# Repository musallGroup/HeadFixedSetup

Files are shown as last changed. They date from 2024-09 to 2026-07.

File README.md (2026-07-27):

# Head-fixed Behavior
This repository contains information about an open-source, multisensory head-fixed setup for operant conditioning. Here, we want to share all relevant information about the setup used in the publication ["Single-trial neural dynamics are dominated by richly varied movements"](https://www.nature.com/articles/s41593-019-0502-4) by Musall et al. One example of using the setup is the [PuffyPenguin](https://github.com/musallGroup/PuffyPenguin) paradigm for multisensory stimulation.

# Overview
Operant conditioning is essential for quantifying animal perception. We developed a head-fixed setup to measure the behavioral output of animals while recording their brain activity with optophysiological and electrophysiological methods. This setup can perform a variety of protocols ranging from auditory, visual, and tactile to multi-sensory stimulation. The protocols themselves are highly customizable so that they can be tailored precisely to the respective research objective.

# Repository structure
```
docs/         MANUAL.md and wiring reference
software/     MATLAB: Autopilot GUI/scale reading, UDP client/server, local Bpod config
firmware/     Arduino/Teensy firmware for the touchshaker and RFID/weighing scale
              (firmware/openscale vendors SparkFun's OpenScale firmware)
hardware/     STL enclosures and Altium/KiCAD PCB design files for the breakout and touchshaker boards
third_party/  Vendored Bpod_Gen2 framework
```
`third_party/bpod_gen2` and `firmware/openscale` vendor third-party projects with local
modifications on top; they are slated to become git submodules pointing at forks once those are
set up. If they've since been converted, initialize them after cloning with:
```
git submodule update --init --recursive
```

# Getting started
1. Clone this repository.
2. Initialize submodules (vendored dependencies): `git submodule update --init --recursive`
3. Follow the [manual](docs/MANUAL.md) to build the hardware and set up the software.

# Installation
Please refer to the [manual](docs/MANUAL.md) for detailed installation steps.

Connections

# Software
The setup runs on MATLAB, with Bpod handling the behavioral state machine. For the full
step-by-step walkthrough of starting MATLAB, calibrating spouts, and running a session, see
[Running a session](docs/MANUAL.md#running-a-session) in the manual.

# Future
Stay tuned for new paradigms and new features of the head-fixed setup. Currently we are working
on automation of data management and mouse detection.

# Citation
If you use this setup in your research, please cite:

> Musall, S., Kaufman, M.T., Juavinett, A.L., Gluf, S., Churchland, A.K. Single-trial neural
> dynamics are dominated by richly varied movements. *Nature Neuroscience* 22, 1677–1686 (2019).
> https://doi.org/10.1038/s41593-019-0502-4

```bibtex
@article{musall2019singletrial,
  title   = {Single-trial neural dynamics are dominated by richly varied movements},
  author  = {Musall, Simon and Kaufman, Matthew T. and Juavinett, Ashley L. and Gluf, Steven and Churchland, Anne K.},
  journal = {Nature Neuroscience},
  volume  = {22},
  number  = {10},
  pages   = {1677--1686},
  year    = {2019},
  doi     = {10.1038/s41593-019-0502-4}
}
```

# License
This project is licensed under the GNU General Public License v3.0 — see [LICENSE](LICENSE) for
details.

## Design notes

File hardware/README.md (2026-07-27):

# Hardware

3D-printable enclosures and PCB design files for the two custom boards used in this setup.

- [`breakout/`](breakout) — Breakout PCB (Altium originals + KiCAD import) and its enclosure
  (box + panels)
- [`touchshaker/`](touchshaker) — Touchshaker PCB (Altium originals + KiCAD import) and its
  enclosure (box + panels)
- [`platform/`](platform) — Animal platform and photodiode holder STLs

See [docs/MANUAL.md](../docs/MANUAL.md) for assembly instructions, wiring diagrams, and how these
parts fit together.

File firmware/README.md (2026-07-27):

# Firmware

Arduino/Teensy firmware for the setup's microcontroller-driven components.

- [`touchshaker/`](touchshaker) — Teensy 4.0 firmware for the Touchshaker box: reads the spout
  lick sensors and drives the spout motors
- [`rfid_scale/`](rfid_scale) — Teensy firmware that reads an RFID tag and a load cell together,
  for automated per-animal weighing
- [`openscale/`](openscale) — Vendored [SparkFun OpenScale](https://github.com/sparkfun/OpenScale)
  firmware, used by the weighing scale hardware

See [docs/MANUAL.md](../docs/MANUAL.md) for how these boards fit into the overall setup.

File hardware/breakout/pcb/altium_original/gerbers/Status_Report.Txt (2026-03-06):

Output: NC Drill Files
Type  : NC Drill
From  : Project [Breakout_v4.PrjPcb]
   Generated File[Breakout_v4-Plated.TXT]
   Generated File[Breakout_v4.LDP]
   Generated File[Breakout_v4.DRR]

Files Generated   : 3
Documents Printed : 0

Finished Output Generation At 07:50:04 On 23.02.2026

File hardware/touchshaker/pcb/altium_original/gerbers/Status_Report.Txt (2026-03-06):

Output: NC Drill Files
Type  : NC Drill
From  : Project [Bpod Controller v5.PrjPcb]
   Generated File[Bpod Controller v5-RoundHoles-Plated.TXT]
   Generated File[Bpod Controller v5-SlotHoles-Plated.TXT]
   Generated File[Bpod Controller v5.LDP]
   Generated File[Bpod Controller v5.DRR]

Files Generated   : 4
Documents Printed : 0

Finished Output Generation At 08:42:49 On 10.02.2026

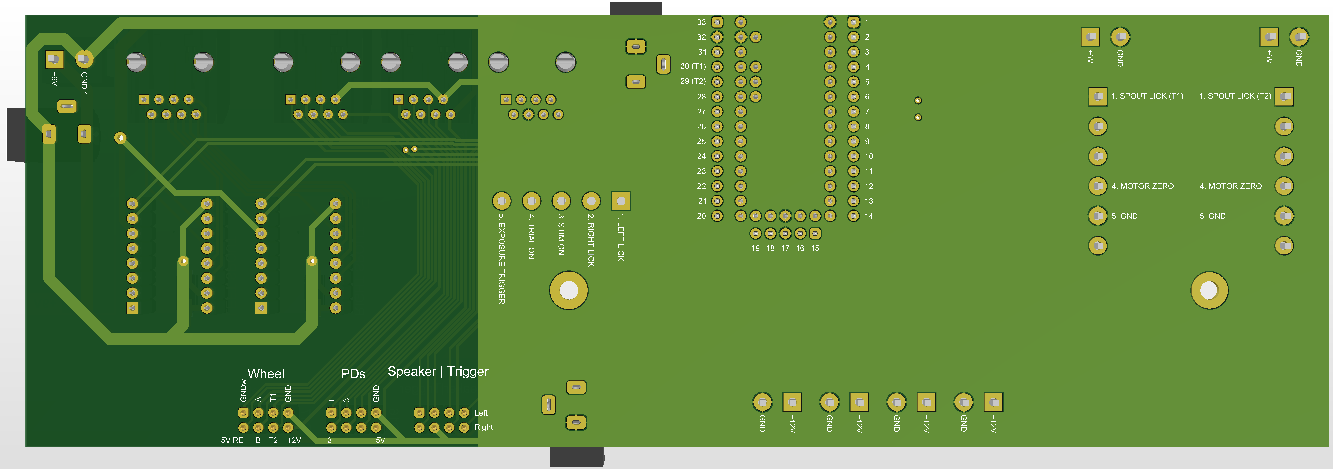
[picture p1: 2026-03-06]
hardware/touchshaker/pcb/altium_original/docs/Bpod_Controller_v5_bottom.png

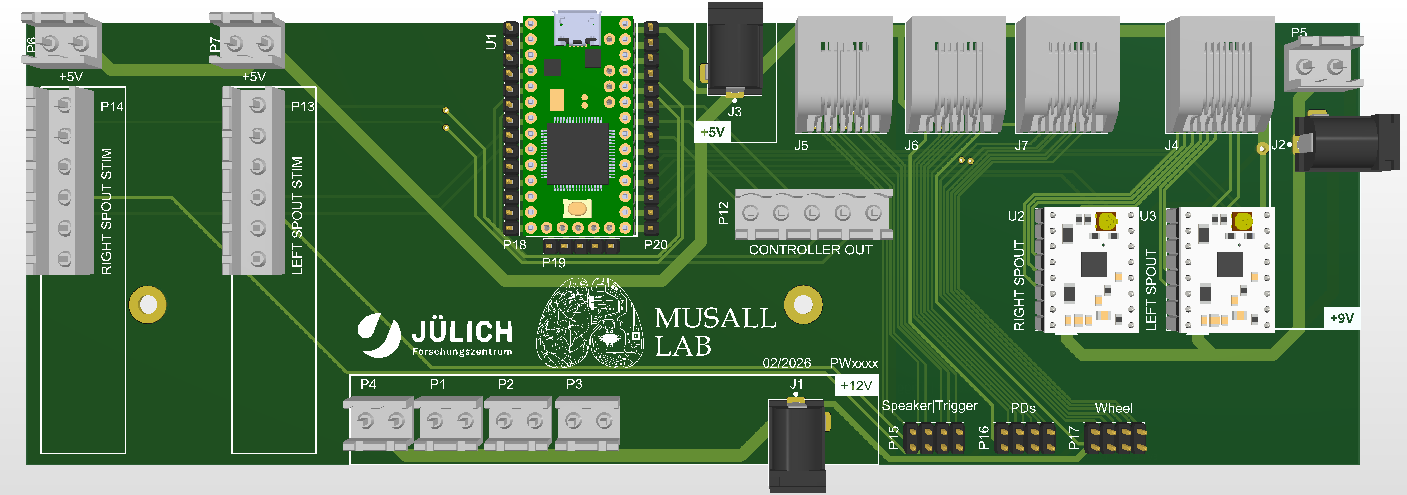
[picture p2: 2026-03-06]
hardware/touchshaker/pcb/altium_original/docs/Bpod_Controller_v5_top.png

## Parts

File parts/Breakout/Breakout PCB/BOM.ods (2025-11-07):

Line # | Name | Description | Quantity | Designator | Manufacturer 1 | Manufacturer Part Number 1
 | 870585774003 | Cap, 47Uf, 50V, Alu Elec, Hybrid, Rad Rohs Compliant: Yes |Wurth Elektronik 870585774003 | 1 | C1 | Wurth Elektronik | 870585774003
 | 10nF 0805 X7R 50V 5% | Kondensator 10nF 0805 X7R 50V 5% | 2 | C2, C4 | Vishay | VJ0805Y103JXAAC
 | 100nF 0805 X7R 100V | Kondensator 100nF 0805 X7R 100V 5% | 2 | C3, C5 | KEMET | C0805C104J1RACAUTO
 | 5569118-1 | Telecom and Datacom Connector, 8 Contact(s), Female, Right Angle, Solder Terminal, Locking, Jack | 4 | J1, J2, J3, J4 | TE Connectivity | 5569118-1
 | SL_1_025_4_ G | Fischer SL_1_025_4_ G, Stiftleiste, 1 Reiheb, 4 Pole, vergoldet | 3 | P1, P2, P3 | Fischer Elektronik | SL 1/025/36G
 | SL_1_025_2_ G | Fischer SL_1_025_2_ G, Stiftleiste, 1 Reiheb, 2 Pole, vergoldet | 11 | P4, P5, P6, P7, P8, P9, P10, P11, P12, P13, P14 | Fischer Elektronik | SL 1/025/36G
 | SL 2 025 8 G | Fischer SL 2 025 8 G, Stiftleiste, 2 Reiheb, 8 Pole, vergoldet | 1 | P15 | Fischer Elektronik | SL 2 025 72G
 | SL_1_025_1_ G | Fischer SL_1_025_1_ G, Stiftleiste, 1 Reiheb, 1 Pole, vergoldet | 4 | P16, P18, P19, P21 | Fischer Elektronik | SL 1/025/36G
 | SL_1_025_3_ G | Fischer SL_1_025_3_ G, Stiftleiste, 1 Reiheb, 3 Pole, vergoldet | 2 | P17, P20 | Fischer Elektronik | SL 1/025/36G
 | 10K 0805 200V 0,25W 0,5% 50ppm/K | Widerstand 10K 0805 200V 0,25W 0,5% 50ppm/K | 7 | R1, R2, R3, R5, R7, R8, R10 | KOA Speer | SG73G2ATTD1002D
 | 100R 1206 200V 0,25W 25ppm/K | Widerstans SMD 100R 1206 200V 0,25W 25ppm/K | 1 | R4 | Yageo Group | RT1206FRD07100RL
 | 5K 0805 100V 0,2W | Widerstand 5K 0805 100V 0,2W 25ppm/K | 2 | R6, R9 | Vishay | PNM0805E5001BST5
 | AT42QT1010-TSHR | Analog Circuit, 1 Func, PDSO6 ; Touchsensor; digital burst mode charge-transfer sensor ; | 2 | U1, U2 | Microchip | AT42QT1010-TSHR

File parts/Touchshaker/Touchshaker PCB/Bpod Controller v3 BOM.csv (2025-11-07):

Line # | Name | Description | Designator | Quantity | Manufacturer 1 | Manufacturer Part Number 1
 | TAJC107K016RNJ | Standard Tantalum, 100 uF, +/- 10%, 16 V, -55 to 125 degC, 2312 (6032 Metric), RoHS, Tape and Reel | C1, C2 | 2 | Kyocera / AVX | TAJC107K016RNJ
 | PJ-102AH | 12V, 2.5A, 2mm Dia | J1, J2, J3 | 3 | Same Sky | PJ-102AH
 | 5569118-1 | Telecom and Datacom Connector, 8 Contact(s), Female, Right Angle, Solder Terminal, Locking, Jack | J4, J5, J6, J7 | 4 | TE Connectivity | 5569118-1
 | 282825-2 | Strip Terminal Block, 15A, 1 Row(s), 1 Deck(s) | P1, P2, P3, P4, P5, P6, P7 | 7 | TE Connectivity | 282825-2
 | 282825-5 | Strip Terminal Block, 15A, 1 Row(s), 1 Deck(s) | P12 | 1 | TE Connectivity / AMP | 282825-5
 | 282825-6 | Strip Terminal Block, 15A, 1 Row(s), 1 Deck(s) | P13, P14 | 2 | TE Connectivity / AMP | 282825-6
 | SL 2 025 8 G | Fischer SL 2 025 8 G, Stiftleiste, 2 Reiheb, 8 Pole, vergoldet | P15, P16, P17 | 3 | Fischer Elektronik | SL 2 025 72G
 | SL_1_025_14_ G | Fischer SL_1_025_14_ G, Stiftleiste, 1 Reiheb, 14 Pole, vergoldet | P18, P20 | 2 | Fischer Elektronik | SL 1/025/36G
 | SL_1_025_5_ G | Fischer SL_1_025_5_ G, Stiftleiste, 1 Reiheb, 5 Pole, vergoldet | P19 | 1 | Fischer Elektronik | SL 1/025/36G
 | Teensy 3.2 | Development Boards & Kits, ARM Teensy 3.2 and header | U1 | 1 | SparkFun | DEV-13736
 | DRV8834 | DRV8834 Low-Voltage Stepper Motor Driver Carrier | U2, U3 | 2 | Pololu | 2134

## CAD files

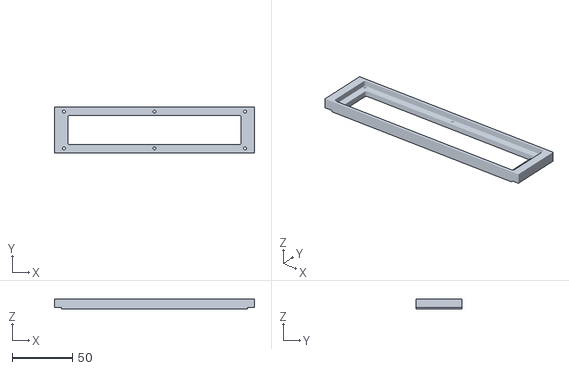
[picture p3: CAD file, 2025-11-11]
hardware/breakout/enclosure/box/Side_Short_v1.stl
166.0 x 38.0 x 8.00

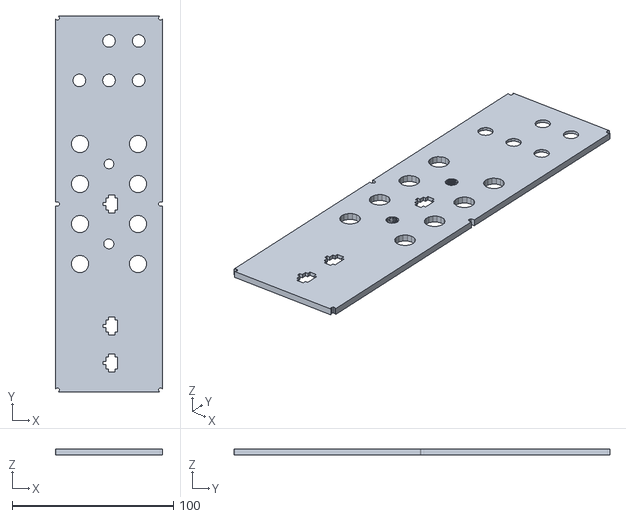
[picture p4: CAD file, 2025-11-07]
hardware/breakout/enclosure/panels/Top_panel_breakout.stl
66.5 x 233.5 x 3.50

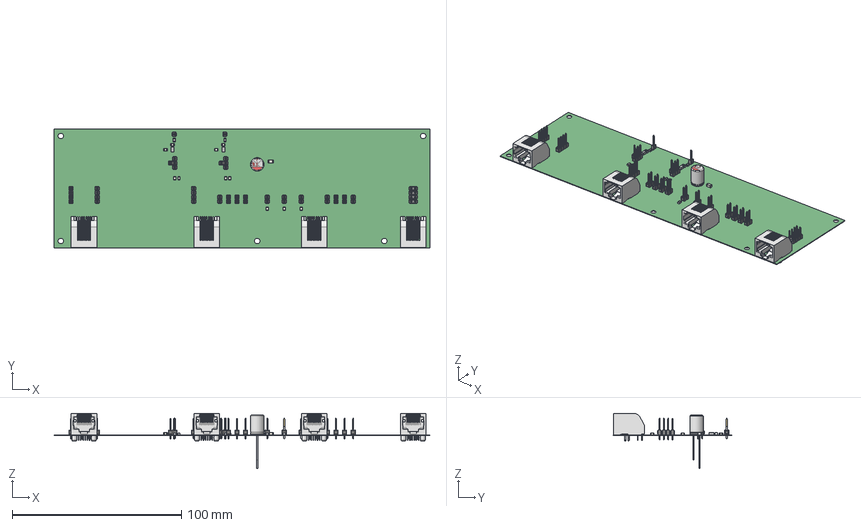
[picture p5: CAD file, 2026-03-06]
hardware/breakout/pcb/altium_original/docs/Breakout_v4.step
222.0 x 70.0 x 32.5 mm
Extruded x 44
F1000S1120M007B x 44
1039929_IPT_000 x 52
1039930_IPT_000 x 52
F1000S1120M009B x 4
J79018822N00001 - EDAC Modular Jack x 4
8x11.5x3.5x0.6

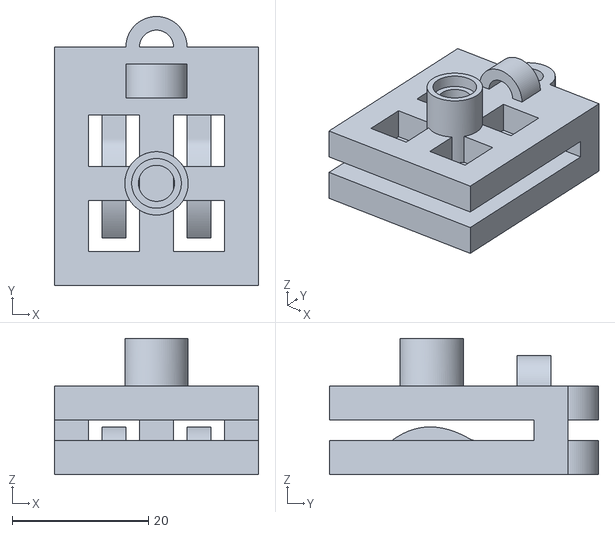
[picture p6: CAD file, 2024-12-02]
hardware/platform/pd_holder_thin.stl
30.0 x 39.5 x 20.0

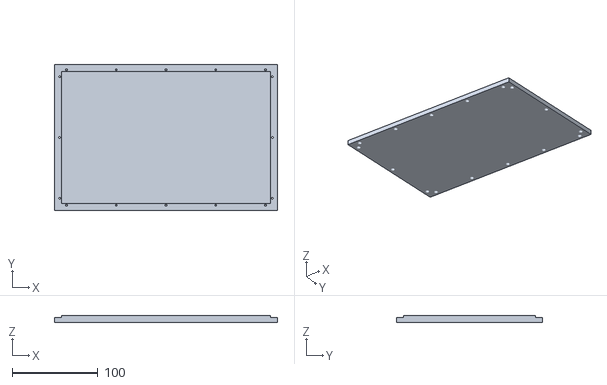
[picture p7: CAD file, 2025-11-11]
hardware/touchshaker/enclosure/box/Bottom_v1.stl
260.0 x 170.0 x 8.00

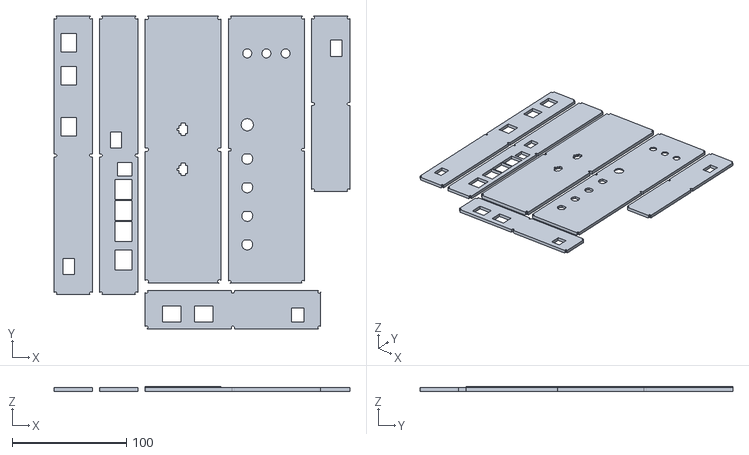
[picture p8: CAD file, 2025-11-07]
hardware/touchshaker/enclosure/panels/Arrange.stl
258.9 x 273.4 x 4.00

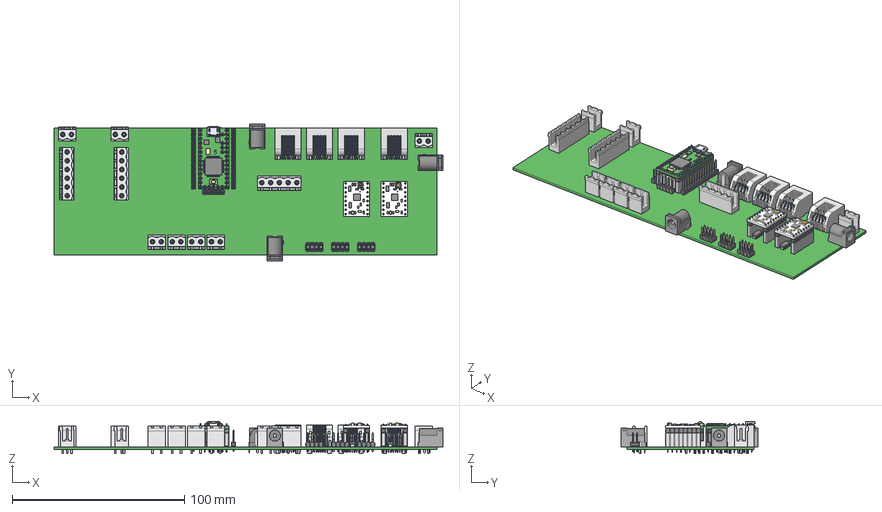
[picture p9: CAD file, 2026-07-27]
hardware/touchshaker/pcb/altium_original/docs/Bpod_Controller_v5.step
225.8 x 79.5 x 18.9 mm
F1000S1120M007B x 65
1039929_IPT_000 x 89
1039930_IPT_000 x 89
F1000S1120M009B x 12
J79018822N00001 - EDAC Modular Jack x 4
drv8834-low-voltage-stepper-motor-driver-carrier x 2
Teensy 3.2 with headers v1
C-282825-6 x 2
C-282825-5
C-282825-2 x 7
CUI_DEVICES_PJ-102AH x 3
Lead x 4

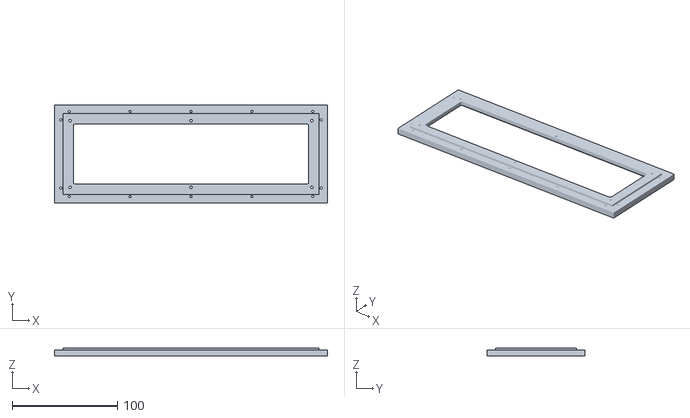
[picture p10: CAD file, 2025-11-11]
hardware/breakout/enclosure/box/Breakout_Lid_v1.stl
260.0 x 93.0 x 8.00

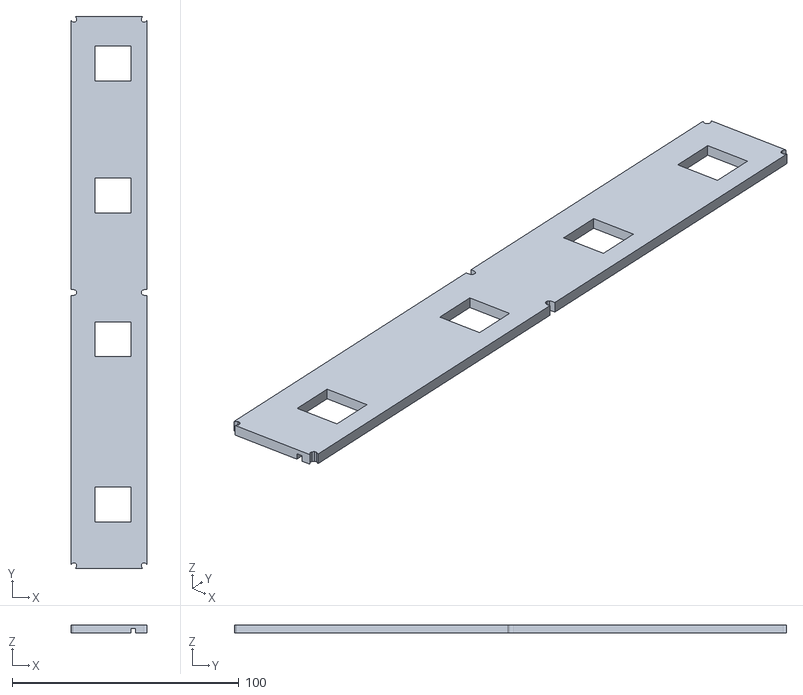
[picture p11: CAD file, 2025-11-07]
hardware/breakout/enclosure/panels/Side_Panel_Breakout.stl
33.5 x 243.5 x 3.50

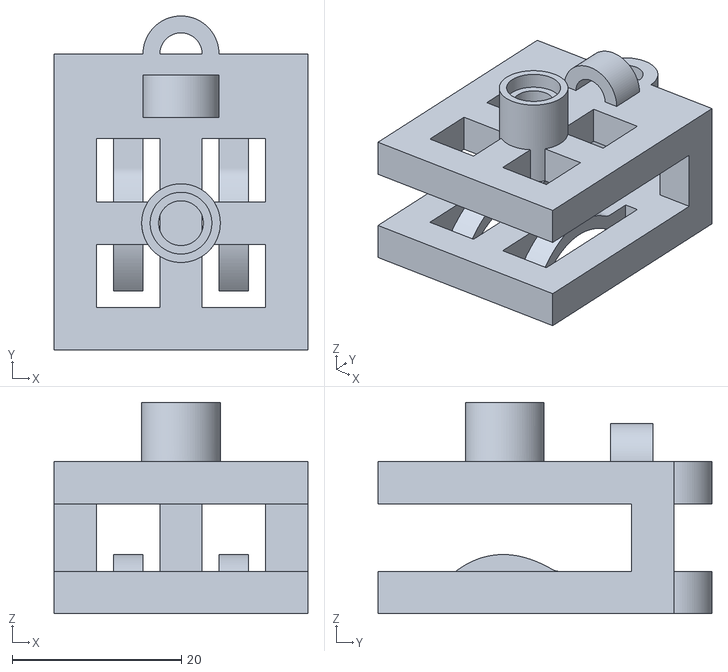
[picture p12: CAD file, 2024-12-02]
hardware/platform/pd_holder.stl
30.0 x 39.5 x 25.0

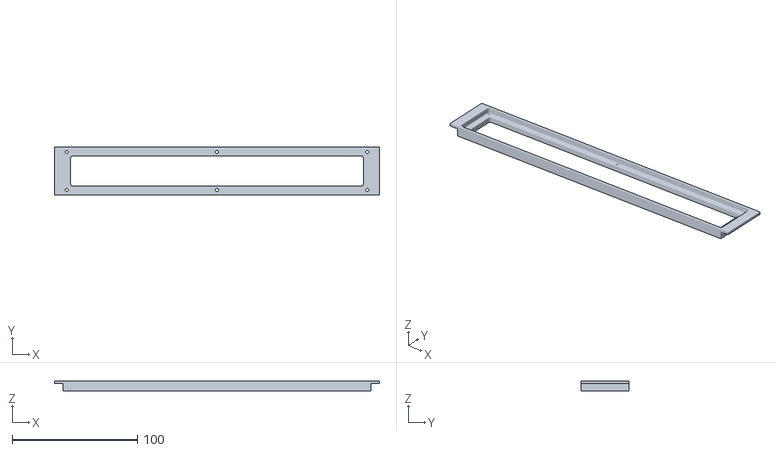
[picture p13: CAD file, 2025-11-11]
hardware/touchshaker/enclosure/box/Side_Long_v1.stl
260.0 x 38.0 x 8.00

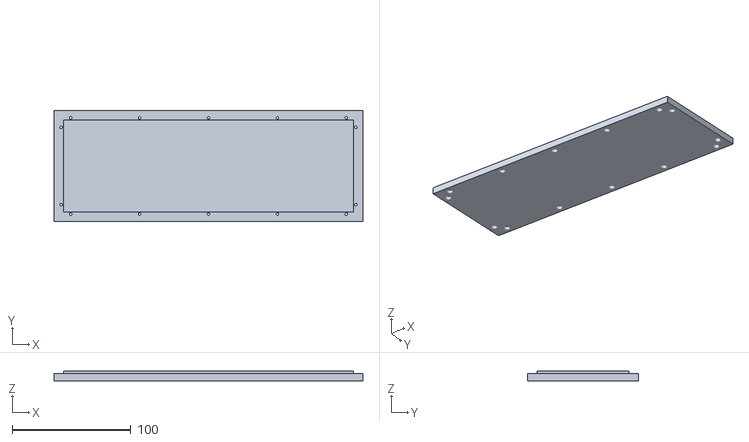
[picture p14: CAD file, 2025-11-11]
hardware/breakout/enclosure/box/Breakout_Bottom_v1.stl
260.0 x 93.0 x 8.00

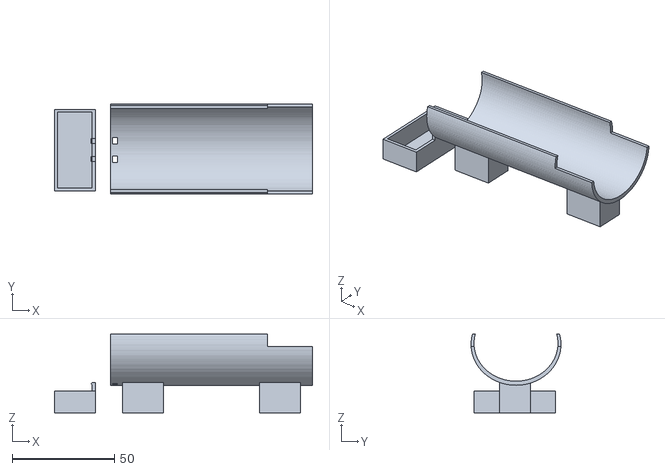
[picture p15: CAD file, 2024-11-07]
hardware/platform/animal_platform.stl
126.2 x 44.0 x 38.5

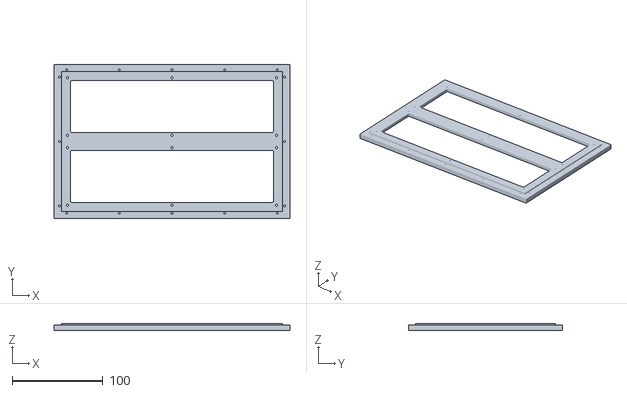
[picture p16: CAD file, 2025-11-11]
hardware/touchshaker/enclosure/box/Lid_v1.stl
260.0 x 170.0 x 8.00

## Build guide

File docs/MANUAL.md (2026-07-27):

# Manual: Head-Fixed Setup

To find 3D designs and print them, see the [`hardware/`](../hardware) folder in this repository.

Our head-fixed setup is composed of different parts which are illustrated one by one in this
manual. All files that you may need during preparation steps are included in this repository.

The sections below follow the order we recommend building in: boxes and platform first, then the
wheel/motors/spouts, then the stimulus and recording systems, and finally the Bpod and Labcams
software setup. Jump to any section directly via the table of contents.

## Requirements

> **TODO(you):** Fill in the actual prerequisites — this section is currently a placeholder.
> - MATLAB version:
> - Required MATLAB toolboxes:
> - Operating system(s) tested:
> - Any other software dependencies:

## Contents

- [Requirements](#requirements)
- [Boxes](#boxes)
  - [Touchshaker Box](#touchshaker-box)
  - [Breakout Box](#breakout-box)
    - [Tools](#tools)
    - [List of components](#list-of-components)
    - [Lid preparation](#lid-preparation)
    - [PCB Preparation](#pcb-preparation)
    - [Photo Diode](#photo-diode)
- [Platform](#platform)
- [Rotary encoder and wheel](#rotary-encoder-and-wheel)
- [Motors and Spouts](#motors-and-spouts)
  - [Spout preparing](#spout-preparing)
  - [Stereo cables](#stereo-cables)
  - [Cable preparation](#cable-preparation)
  - [Wiring of the signal wires](#wiring-of-the-signal-wires)
  - [Wiring of the zero-position wires](#wiring-of-the-zero-position-wires)
  - [Grounding](#grounding)
  - [Test your signal](#test-your-signal)
- [Tactile stimuli system](#tactile-stimuli-system)
- [Air-Puff Delivery](#air-puff-delivery)
- [Visual stimuli system](#visual-stimuli-system)
  - [Visual stimuli components](#visual-stimuli-components)
- [Auditory stimuli system](#auditory-stimuli-system)
  - [Auditory stimuli components](#auditory-stimuli-components)
- [Water providing system](#water-providing-system)
- [Camera and recording system](#camera-and-recording-system)
  - [First step: IR filter removal](#first-step-ir-filter-removal)
  - [Second step: Mounting the camera](#second-step-mounting-the-camera)
  - [Third step: Lens mounting](#third-step-lens-mounting)
  - [Fourth step: Mounting the IR LED](#fourth-step-mounting-the-ir-led)
  - [Optional step: Mounting the IR mirror](#optional-step-mounting-the-ir-mirror)
- [Bpod system](#bpod-system)
- [Running a session](#running-a-session)
- [Labcams installation](#labcams-installation)

## Boxes

This setup uses two customized PCBs (Printed Circuit Boards):
1. Touchshaker PCB (also referred to as the Spout controller PCB)
2. Breakout PCB

These two PCBs are housed within custom enclosures equipped with appropriate sockets and
connected via Ethernet cables.

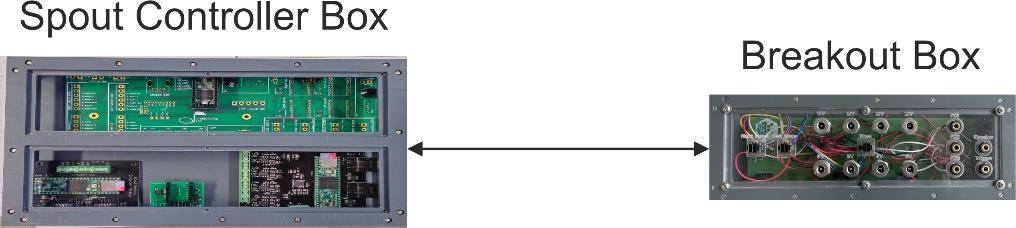
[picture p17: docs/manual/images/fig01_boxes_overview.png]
The boxes schematic and their connection


> **TODO(you):** A photo of the fully assembled setup (platform, wheel, both boxes, cameras) would
> help builders know what they're aiming for before starting. Add one here if you have it.

In order to prepare each box, follow these instructions:

### Touchshaker Box

> The original build figures and hardware silkscreen label this the "Spout controller Box" — it's
> the same enclosure referred to as the **Touchshaker box** everywhere else in this manual, in
> `docs/connections.png`, and in [`hardware/touchshaker/`](../hardware/touchshaker).

- Touchshaker PCB
- Bpod Teensy shield
- Bpod input module
- Bpod rotary encoder module
- Box (assemble the box based on the location of modules and prints over the panels of the box)

After you assemble the box, put all components in the box. The box is then ready to be connected
to the breakout box using Ethernet connections.

> **TODO(you):** This section is thinner than Breakout Box below — it has no Tools or step-by-step
> assembly. Add the tools list and build steps here if you'd like it at the same level of detail.

### Breakout Box

#### Tools

- Soldering iron
- Crimping tool
- Side cutter
- Screw drivers
- "Helping hand"

#### List of components

- Custom Breakout PCB
- Custom surrounding box
- 8x [Power Jacks RND](https://www.distrelec.ch/de/power-jacks-rnd/pf/2017224)
- 5x [Phone Audio connector, 3 Contacts, Jack, 3.5 mm](https://de.farnell.com/pro-signal/mj-073h/klinkenbuchse-3-5mm-3pol/dp/1267396?pf_custSiteRedirect=true)
- 3x [Plug Housing, Dual Row, with Panel Mount Ears, 4-Circuits](https://de.rs-online.com/web/p/steckergehause-und-stecker/2332810)
- 26x Oval-Head M3x8 SS
- 12x [Crimp Terminal, Male, with Select Gold (Au) Plated Tin/Brass Alloy](https://de.rs-online.com/web/p/crimpkontakte/6794782)
- 4x [Modular Telephone Jack, 8P8C Right Angle, PCB](https://www.digikey.de/en/products/detail/adam-tech/MTJ-881X1/9832263)
- Solder
- [26 AWG Wire (different colors)](https://de.rs-online.com/web/p/schaltdraht/7417979?gb=s)

Inside this box you just have the breakout PCB:

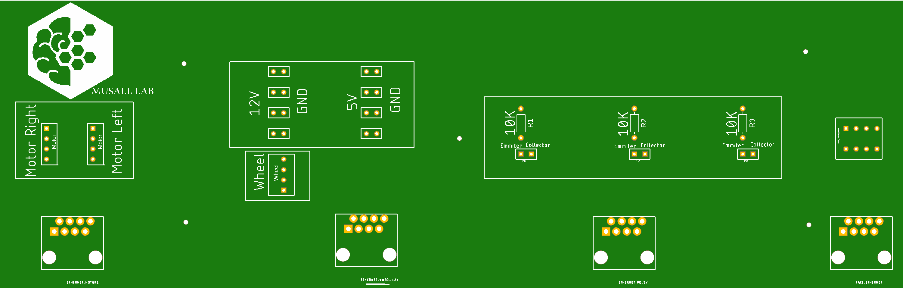
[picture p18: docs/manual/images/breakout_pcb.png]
Breakout PCB


The box consists of 3 main parts:
1. Motors
2. Wheel and power sources
3. Photo diodes

#### Lid preparation

Fasten all audio connectors and power jacks to the dedicated holes in the lid using the enclosed
screw nuts.

To prepare the power source connections, the pins must be soldered to ~10 cm long 26 AWG wires
as follows:

- Long pin → GND holes
- Short pin → Positive holes

De-isolate ~2 mm at the end of each wire and put some solder on the ends. Fill the connections of
the power jacks with solder as well. Now melt the solder on the power jack connections again and
insert one end of a wire each. Wait until hardened and use a shrinking tube to isolate the
connection. Repeat this for the audio connections.

For the plug housing, start preparing the wires as before. Then use a crimp tool to attach the
wires to the male crimp terminals. To ensure a proper connection, merge the wire and the crimp
terminal with a small amount of solder. Ensure that no stripped wire is outside of the crimp
terminals and that it is only in the crimped area (not in the tip of the crimp terminal). Now
push the prepared crimp terminals into the plug housing. Afterwards, push the housings into the
dedicated spots in the lid.

#### PCB Preparation

Push the RJ45 Ethernet jacks into the dedicated spot of the PCB and solder the pins to the
contacts of the PCB.

| | |
|---|---|
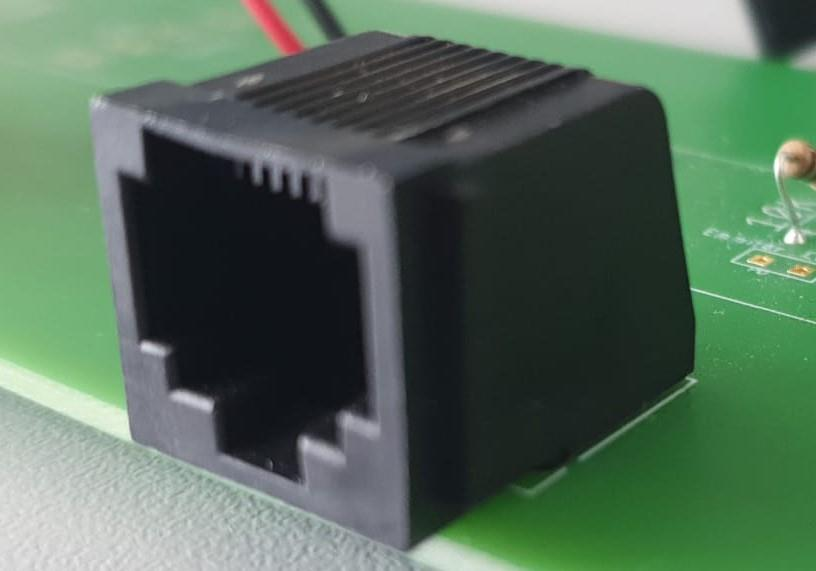
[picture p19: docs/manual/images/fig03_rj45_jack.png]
Soldered telephone jack
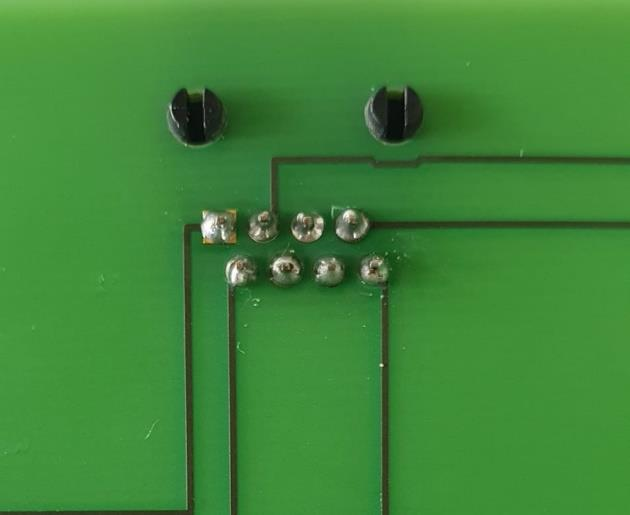
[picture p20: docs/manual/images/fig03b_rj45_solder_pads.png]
RJ45 solder pads
|  |  |

Connect the other end of the wires that you soldered to the plugs to the associated holes in the
PCB, and fixate them by soldering them to the contacts:

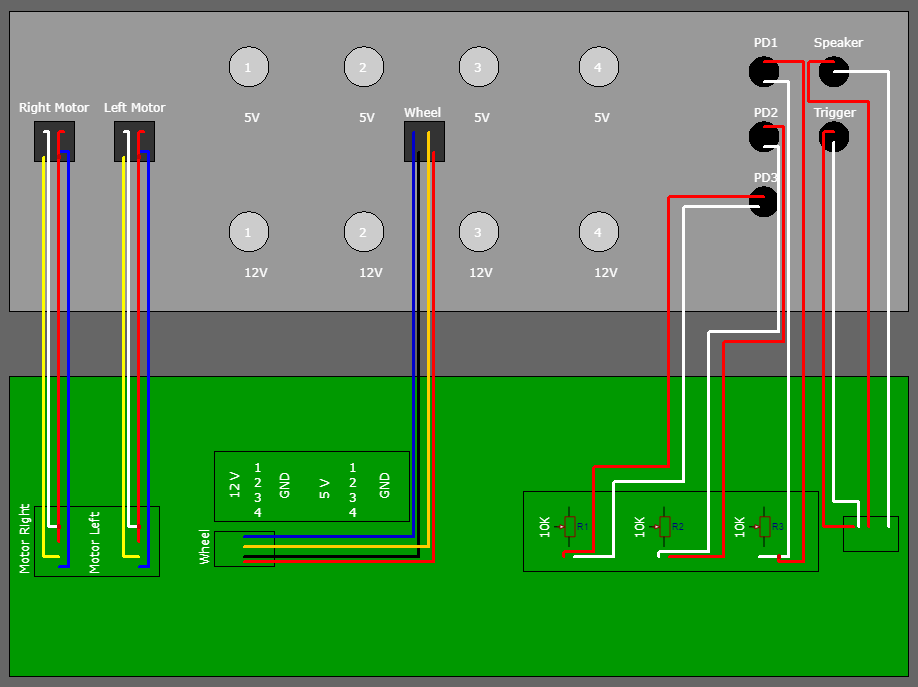
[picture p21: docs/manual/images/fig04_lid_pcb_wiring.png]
Schematic of the connections between lid and PCB (exemplary color code)


Put everything in the box and glue the telephone jacks to the panel. When the glue has dried,
screw all panels to the box.

#### Photo Diode

The following picture shows the general configuration of a photo diode.

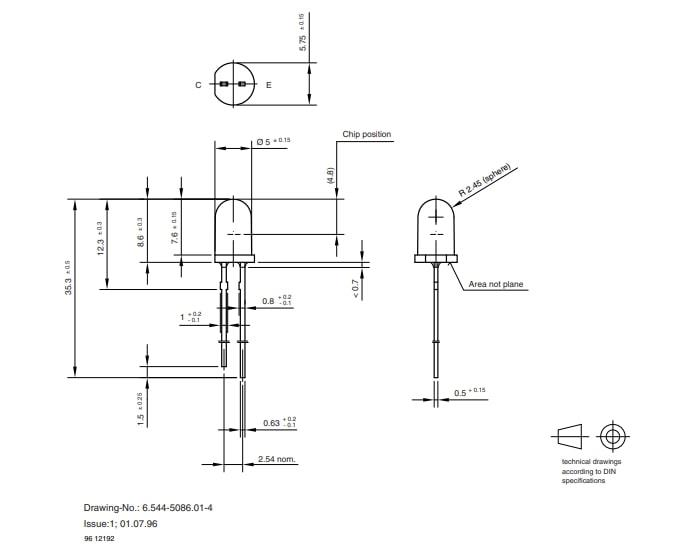
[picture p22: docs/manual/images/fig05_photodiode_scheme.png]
General scheme of a photo diode


**First step: Wire up the photo diode**

To wire up the photo diode, start by removing the cable jacket of the stereo cable. Next, solder
the longer pin of the photo diode to the white wire and the shorter pin to the red wire. Note that
the shielding (small surrounding wires) should be left unconnected in this specific case.

In summary:
- White wire: Anode / Longer pin / Emitter
- Red wire: Cathode / Shorter pin / Collector

The following pictures show the process and final result:

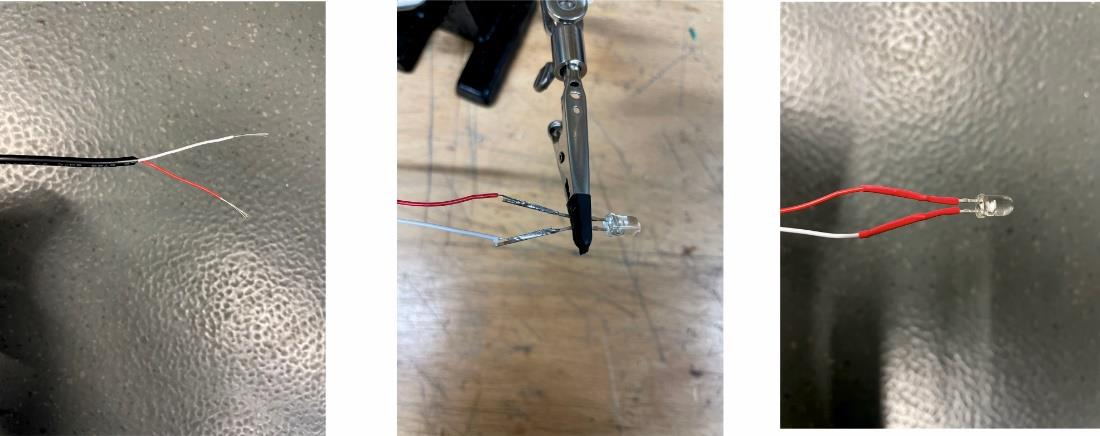
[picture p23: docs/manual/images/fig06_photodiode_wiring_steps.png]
Preparation steps to connect the photo diode


**Second step: Preparing the breakout PCB section**

There is a section on the breakout PCB related to the photo diode, to which you need to solder
the components. The first component is a set of 10k resistors, in the positions marked below:

Breakout PCB with photo diode resistor positions

There are three stereo sockets in the lid of the breakout box that are dedicated to the PDs.
Solder the respective stereo pins of the plug to the emitter/collector holes in the PCB via a
cable.

**Third step: Preparing the Touchshaker box**

As mentioned before, there is a dedicated Ethernet connection for PDs between the breakout box and
the Touchshaker box. As a final step you need to prepare the Ethernet socket on the Touchshaker
side. If you consider the Ethernet breakout board as below:

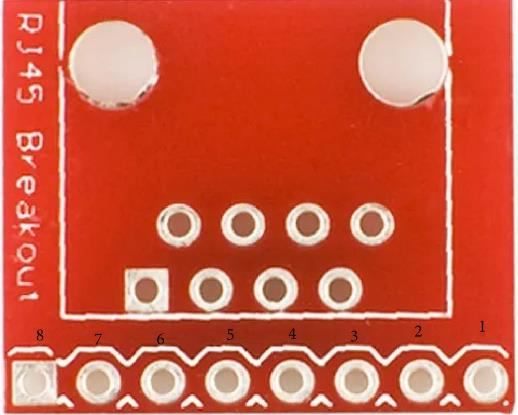
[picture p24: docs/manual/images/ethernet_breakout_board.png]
Ethernet breakout board


In order to prepare the PD Ethernet socket in the Touchshaker box, you need to solder three wires
to pins 8 / 7 / 6 and connect them to the positive pins on the Bpod input module inside the
Touchshaker box. Alternatively, you can solder the cables directly to an Ethernet socket in the
box.

In summary:
| Ethernet breakout board pin | Bpod input module |
|---|---|
| Pin 8 | 1+ input channel |
| Pin 7 | 2+ input channel |
| Pin 6 | 3+ input channel |
| Pin 2 | 1-, 2-, 3- input channels |

## Platform

The platform is the base that everything else — boxes, wheel, spouts, cameras — mounts to.

- Thorlabs platform
- Thorlabs poles
- Thorlabs base

Assemble poles on the platform for each component of your setup that you want to fix to the
platform. You may need to adjust their positions later to ensure that everything fits properly and
you get proper videos of your test subjects.

## Rotary encoder and wheel

The wheel lets the animal run/walk during a session while the rotary encoder reports its motion
to the Breakout Box.

- Wheel (3D-print)
- Wheel holder (3D print)
- Rotary encoder
- Rotary encoder holder (3D print)

1. Attach the wheel to the wheel holder.
2. Attach the rotary encoder to the rotary encoder holder.
3. Attach the wheel to the rotary encoder using the wheel holder.
4. Attach a Thorlabs pole to the rotary encoder holder.
5. Place everything on the platform.
6. Connect the rotary encoder to the Breakout Box using the "Wheel" 4-pin plug on the Breakout
   box. (You need to prepare the rotary encoder cable with a male 4-pin jack.)

## Motors and Spouts

Stepper motors position the spouts, and the spouts themselves double as lick sensors.

- Stepper motors
- Spouts
- Spout holders (3D design)
- Motor holder (3D design)
- Motor wires (depends on the motor type)
- Shrinking tubes
- Stereo cables
- 4-pole crimp connectors + housings (female and male)
- Optional: [specific core wires with multiple small wires](https://www.aliexpress.com/item/33022308653.html)
  for improved cable management

**First step: Prepare your motor wiring**

Remove the cable jacket to access the 8 small wires inside it. Connect these 8 small wires to two
different male 4-port connection sockets. Connect 4 wires of each motor to a female 4-port
connection socket.

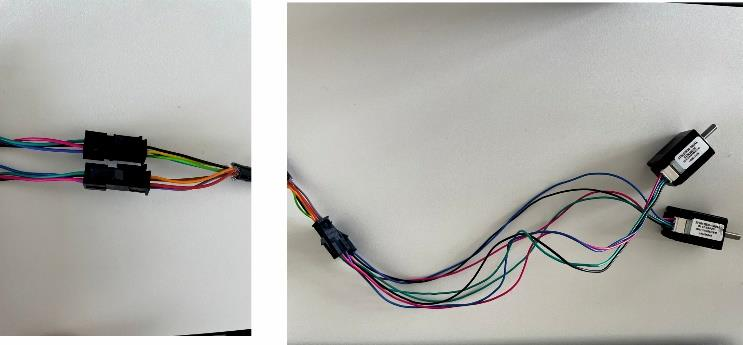
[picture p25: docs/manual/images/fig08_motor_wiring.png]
Motor wiring


**Second step: Connect the free end to the breakout PCB using the following order.**

Be aware that the color coding of motors is important in this step. Depending on the motor you are
using, you may have 4 different colors of wire per motor:

- German version: red / blue / yellow / orange
- US version: black / green / blue / red

After checking all color codes, solder the free end to the PCB in this order (from top): Black /
Green / Blue / Red.

### Spout preparing

The finished spout assembly looks like this; the steps below cover wiring it for lick detection
and zero-position sensing.

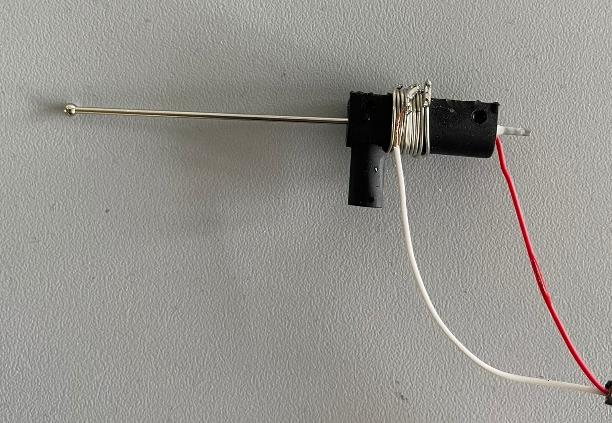
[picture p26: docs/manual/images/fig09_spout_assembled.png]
Assembled spout


### Stereo cables

For each lick detection system, 3 stereo cables are needed:

| Cable | Purpose |
|---|---|
| Cable 1 | Signal 1 |
| Cable 2 | Signal 2 |
| Cable 3 | Zero position and grounding |

### Cable preparation

Take off the plastic shielding on all three stereo cables. Each cable will reveal two wires: red
and white (or yellow). The red wire carries the desired (licking) signal.

### Wiring of the signal wires

Select the red wire from the stereo cables and solder it to the end of the metal body of the spout
(you can wrap it around the spout first and then solder it). Ensure that the soldered part fits
securely inside the spout holder. Finally, use a shrinking tube to secure and stabilize the
connection.

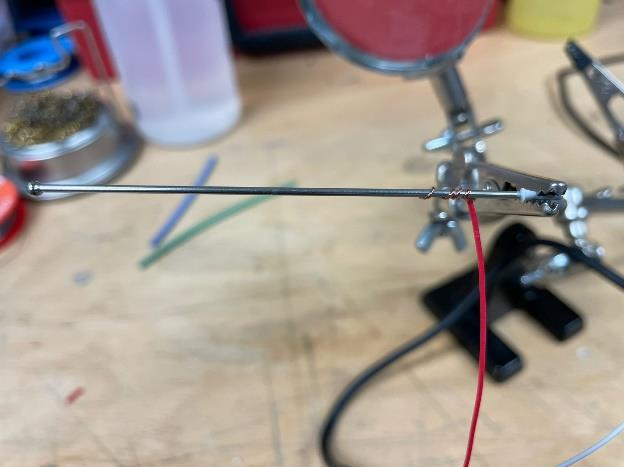
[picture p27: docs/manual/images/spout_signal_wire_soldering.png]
Soldering the spout signal wire


Now connect your stereo cable to the stereo sockets labeled "Spout Left" and "Spout Right" on the
Touchshaker box.

### Wiring of the zero-position wires

Insert the spout into the holder and fasten it by screwing it tightly. Then wrap a metal wire
around the spout holder to provide additional stability. Solder the white wire from cable 3 to the
wrapped wire of spout 1, and solder the red wire from cable 3 to the wrapped wire of spout 2.

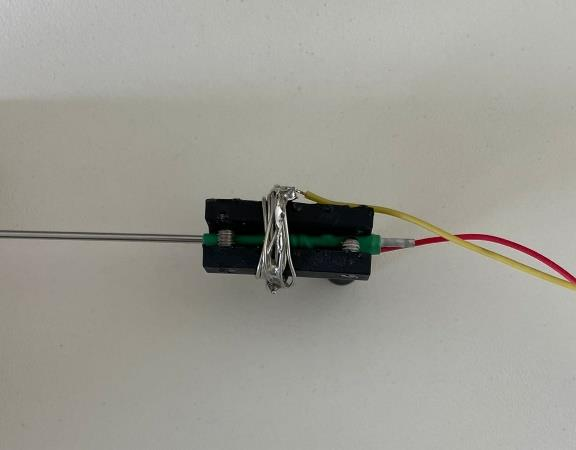
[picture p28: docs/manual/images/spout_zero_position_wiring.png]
Zero-position wire wrapped around the spout holder


### Grounding

On each motor holder there are designated spots where screws need to be inserted. Take the
shielding cables from the third stereo cable and solder them to both screws on the motor holder.
Connect the third cable to the "Motor Zero" socket on the Touchshaker box.

Congratulations! Your spout is now successfully assembled and ready to be used.

### Test your signal

Attach the spouts on top of the motor holder carefully, since holders are fragile. To test the
spouts, run the paradigm using Bpod and change the position of the spout using the GUI.

Furthermore, to verify the adequacy of the licking signal, open the Arduino IDE, run
[`firmware/touchshaker/TouchShaker/TouchShaker.ino`](../firmware/touchshaker/TouchShaker/TouchShaker.ino),
and open the serial monitor. Signals without any licks should resemble:

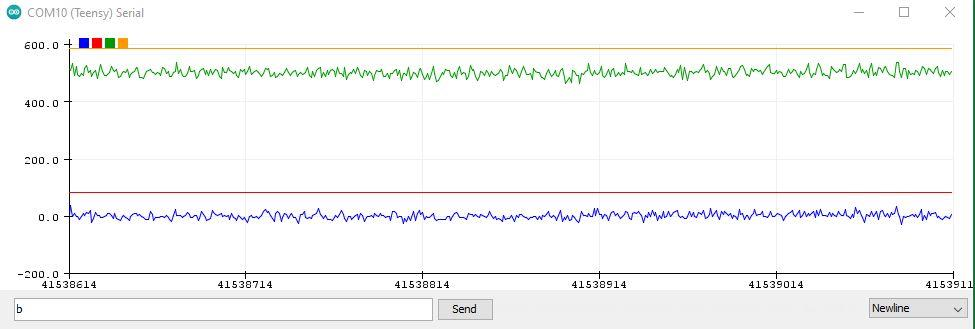
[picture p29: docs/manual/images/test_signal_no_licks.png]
Serial monitor signal without licks


If the signals appear noisy or distorted, double-check the connections and soldered spots
meticulously to ensure a proper and stable connection.

Next, gently touch the top of each spout with a slightly wet finger. You should observe a signal
similar to:

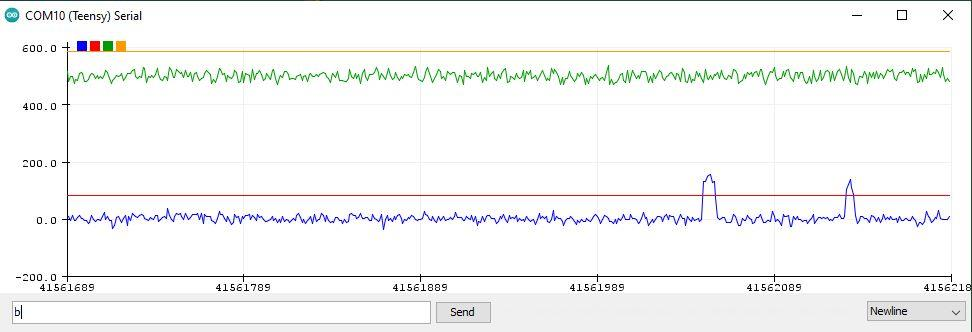
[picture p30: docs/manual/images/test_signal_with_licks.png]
Serial monitor signal with licks


## Tactile stimuli system

This is the pneumatic (air-puff) delivery system; see [Air-Puff Delivery](#air-puff-delivery)
below for the stimulus parameters used in practice.

> **Safety:** Compressed air systems can pressurize unexpectedly. Never point the outlet at
> yourself, others, or an animal outside of a controlled stimulation, wear eye protection while
> testing, and fully depressurize the system before disconnecting tubing.

- Spouts
- Spouts holder (3D design)
- Bpod port interface
- Tubes
- T-connector
- Valves
- Air compressor system
- Air pressure regulator

To set up the pneumatic tactile feedback system, follow these detailed steps:

1. **Connect the pressure regulator to the compressor system.** Take a suitable air tube and
   connect one end to the output port of the air compressor. Attach the other end of the tube to
   the input port of the pressure regulator. Ensure the connection is secure to prevent air leaks.
2. **Mount the valve to the Bpod port interface.** Locate the Bpod port interface on your system.
   Securely mount the solenoid valve to the designated port on the Bpod interface, ensuring it is
   properly aligned and firmly attached.
3. **Connect the tubing.** Attach one end of a tube to the output port of the pressure regulator
   and connect the other end to the first input port of the valve. From the second output port of
   the valve, connect a soft, flexible tube long enough to reach your desired location without
   causing delays or pressure drops. Attach the free end of this soft tube to the air puff
   connection on the camera holder.

**Detailed steps with additional considerations:**

1. *Connecting the pressure regulator:* Ensure the air compressor is turned off before making any
   connections. Check that the pressure regulator is rated for the output pressure of your
   compressor. Use hose clamps if necessary to ensure airtight connections between the compressor
   and the pressure regulator.
2. *Mounting the valve:* The Bpod port interface typically has specific slots or connectors for
   mounting peripherals — refer to the Bpod documentation for exact mounting procedures.
3. *Connecting the tubing:* Cut the tubing to the required lengths using a sharp utility knife to
   avoid uneven edges which could cause leaks. Secure all tubing connections with appropriate
   fittings or hose clamps. Double-check all connections for tightness — loose connections can
   lead to loss of pressure and ineffective tactile feedback.

**Final checks and testing:**

- *System integrity:* After all connections are made, ensure the entire system is securely
  connected and there are no potential points for air leakage.
- *Pressure adjustment:* Adjust the pressure regulator to the desired level suitable for your
  tactile feedback requirements.
- *Operational test:* Turn on the compressor and check for leaks. Then operate the system to
  ensure that the valve correctly modulates air flow to the air puff connection on the camera
  holder.
- *Calibration:* If necessary, calibrate the system by adjusting the regulator and valve settings
  to achieve the desired tactile stimulus.

## Air-Puff Delivery

Air-puff stimuli were delivered using solenoid valves (NPV2-1C-03-12, Clippard, USA) connected to
compressed air sources via silicone tubing (inner diameter: 1 mm; outer diameter: 3 mm). Air was
directed through blunt-ended cannulas with an outlet diameter of 1 mm. The cannula tip was
positioned 1 cm from the animal's face.

The cannula was oriented at an angle of 35° relative to the horizontal plane, directing airflow
from above toward the whisker pad while minimizing direct stimulation of the eyes. Depending on
the experimental objective, the cannula position can be adjusted to target different facial
regions.

Two behavioral setups were used, differing in tubing length and pneumatic configuration. To
compensate for these differences, air pressure was adjusted individually for each setup (2.0–2.2
bar) to achieve comparable airflow intensity at the animal. Because the effective stimulus
strength depends on multiple factors, including valve characteristics, tubing length, tubing
diameter, and tubing material, pressure values alone are not sufficient to fully characterize the
stimulus. Instead, the airflow reaching the animal should be calibrated empirically for each
setup.

For sensory stimulation experiments, air-puff durations of 20 ms or 70 ms were used depending on
the experimental paradigm. Air-puff intensity can be modulated by varying pulse duration, applied
pressure, or both. In addition to their use as sensory stimuli, longer-duration or higher-intensity
air puffs can be employed as aversive feedback during behavioral training.

## Visual stimuli system

### Visual stimuli components

- Monitor
- Monitor holder (3D design)
- Cables

Two/one monitor(s) must be mounted in front of the wheel/platform. They only need to be connected
to the PC and supplied with power. Visual stimuli are executed by external Python code.

> **TODO(you):** The Python code that drives visual stimuli isn't in this repository. Add it
> under `software/`, or replace this note with a link to wherever it's maintained.

## Auditory stimuli system

### Auditory stimuli components

- Stereo speakers
- BNC sockets
- BNC cables

To enable auditory stimulation, a BNC connection to the Bpod output module is required. Follow
these steps to connect both cables to the unsoldered BNC socket, then prepare and solder the BNC
sockets to a stereo socket as illustrated below:

1. For each BNC socket, attach a red wire to the central pin (referred to as main wires 1 and 2).
2. Connect a shared wire to the smaller pins of both BNC sockets.
3. Stereo sockets have 4 pins; the top and bottom ones are the main ones. Connect main wire 1 and
   main wire 2 from the BNC sockets to these pins.
4. Attach the shared wire to one of the remaining pins in the stereo sockets.
5. Plug the stereo cable from the speakers into the stereo socket.

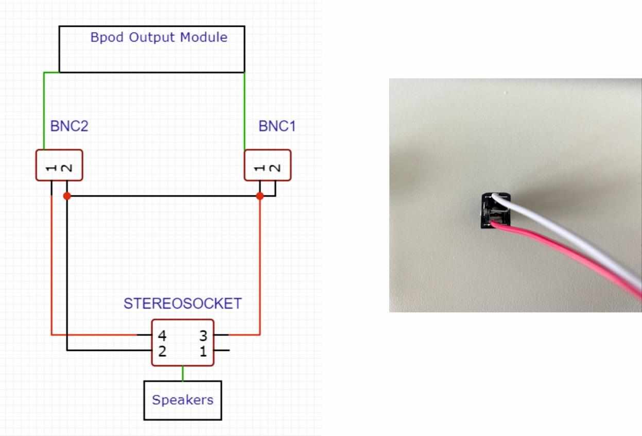
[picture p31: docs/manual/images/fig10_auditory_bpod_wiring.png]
Illustration of the Auditory-Bpod connections


## Water providing system

The water system delivers reward through the spouts, gravity-fed from a syringe via a three-way
valve and Bpod-controlled valves.

- Tubes
- Syringe
- Syringe holder (3D design)
- Three-way valve
- Valves
- T-connector

Assemble the system as follows:
1. Attach the Bpod port interfaces with the valves to the T-shaped part of the syringe holder with
   glue.
2. Attach the three-way valve to the syringe and insert it into the holder.
3. Connect the three-way valve to the T-connector with a tube.
4. Connect both other ends of the T-connector to the middle input of a valve each, using tubes.
5. Close the input closest to the metal piece of the valves using a tied-up piece of tube.
6. Connect the output of the valves to the spouts using tubes.
7. Connect the Bpod port interfaces to the state machine with an Ethernet cable.

## Camera and recording system

- Camera (we use FLIR Chameleon 3.0 or FLIR Firefly)
- Camera cable
- Custom camera mount
- IR LED
- IR LED holder (print)
- IR mirror
- IR mirror holder (print)

For video recording in each experimental session, we use 2 cameras per setup. Since we use IR
LEDs within the setup, we need to remove the IR filter of all cameras, in the following order:

### First step: IR filter removal

> **Safety:** Hot air guns get hot enough to burn skin and damage nearby components. Keep the tip
> moving, avoid prolonged contact with the PCB, and let the camera cool before handling it.

Open the camera carefully. Usually, the CMOS (Complementary Metal-Oxide-Semiconductor) inside the
camera is extremely sensitive. Use a hot air gun to loosen the glue used to fix the filter, remove
the filter, and close the camera.

| | |
|---|---|
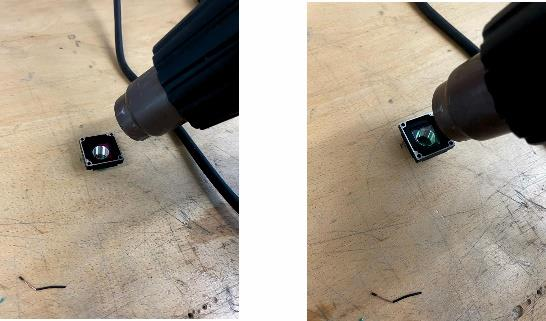
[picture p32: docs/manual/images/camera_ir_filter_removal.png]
Loosening the IR filter with a heat gun
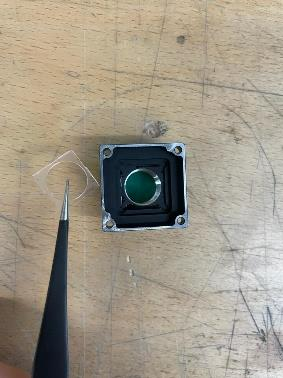
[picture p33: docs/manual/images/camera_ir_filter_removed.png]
IR filter removed
|  |  |

### Second step: Mounting the camera

To securely mount the lens onto the camera, install the camera on top of the mounting piece (you
will need very small screws for this step).

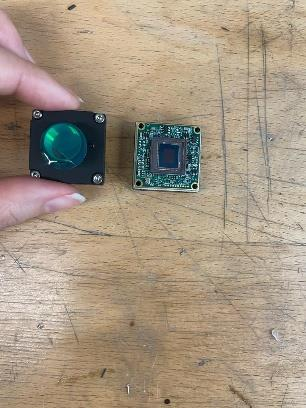
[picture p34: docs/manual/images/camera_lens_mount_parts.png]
Camera and lens mount parts

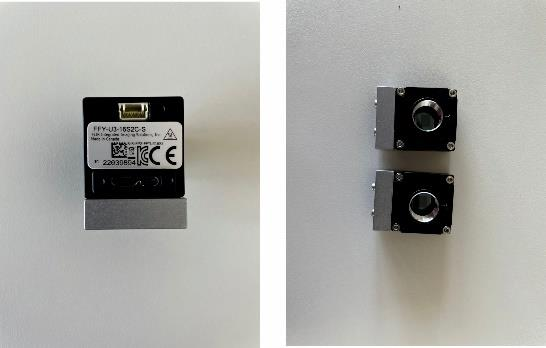
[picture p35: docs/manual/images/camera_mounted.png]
Mounted cameras


### Third step: Lens mounting

Each lens has a fixation ring which needs to be installed first. There is a small screw on top of
the camera lens holder which you need to unscrew first to fit the lens. Screw the lens into the
camera.

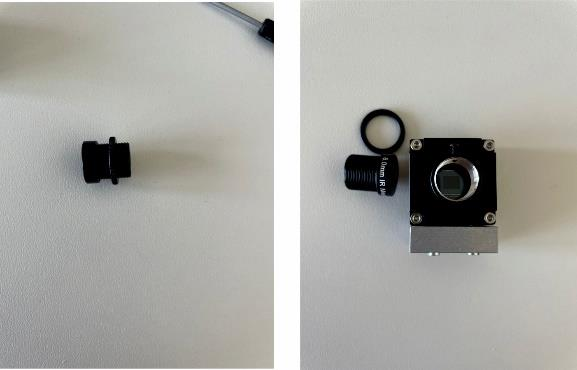
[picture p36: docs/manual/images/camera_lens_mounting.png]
Lens mounting parts

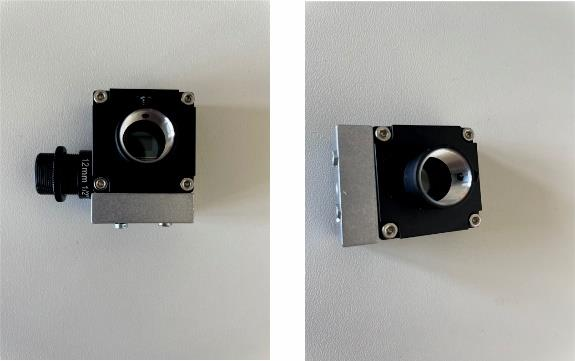
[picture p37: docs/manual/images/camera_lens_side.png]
Lens mounted, side view

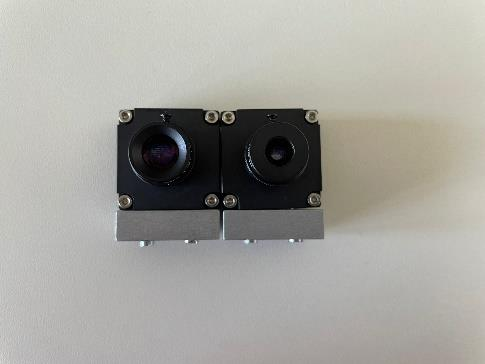
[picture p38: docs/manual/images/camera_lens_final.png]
Two cameras with lenses mounted


Now connect the camera to the PC and adjust the field of view and sharpness for the platform where
the animal will sit later (tip: use a dummy for this). Use SpinView for this purpose — see the
Labcams installation section below for setup instructions.

### Fourth step: Mounting the IR LED

After printing the IR LED mount, mount the LED on it and fix it using small screws. Each camera
needs one IR LED. Check that the lighting in your video is adequate and adjust its direction as
needed by checking the camera view in SpinView.

### Optional step: Mounting the IR mirror

Depending on your setup, you can use an IR mirror for a better view of facial movements. Print the
IR mirror holder, stick an IR mirror on top of it, and adjust its direction using SpinView.

## Bpod system

- Bpod state machine (here we use Bpod State Machine r2.5)
- Bpod input module
- Bpod output module
- Bpod port interface
- Bpod Teensy shield
- Bpod ambient module
- Bpod rotary encoder module

The first step is to connect the various components of Bpod, as illustrated below:

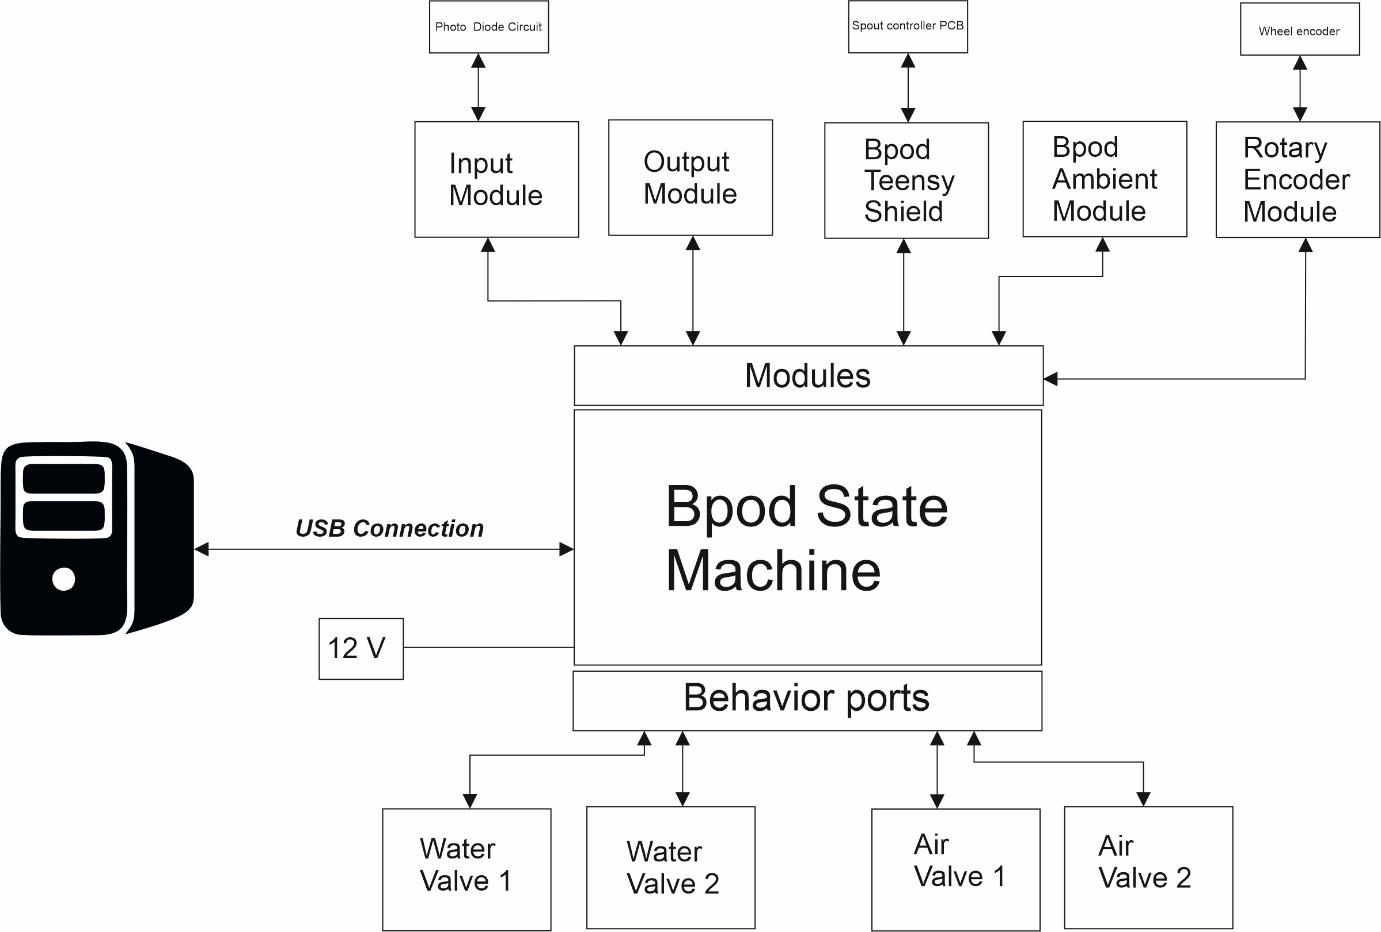
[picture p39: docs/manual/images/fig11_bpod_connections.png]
Illustration of the necessary Bpod connections


After connecting all the components, set up Bpod on your PC using MATLAB:

1. Bpod_Gen2 is already vendored in this repository at
   [`third_party/bpod_gen2`](../third_party/bpod_gen2) (originally from
   [github.com/sanworks/Bpod_Gen2](https://github.com/sanworks/Bpod_Gen2)).
2. Add `third_party/bpod_gen2` to the MATLAB path.
3. Run `Bpod()` at the MATLAB command prompt.

You are all set to run Bpod.

## Running a session

1. Start MATLAB and enter `bpod` at the command prompt — this opens the Bpod GUI.
2. Flush the spouts, then press **Start** once flushing is done. (Flush calibration only needs to
   be redone occasionally.)
3. Choose your paradigm/protocol, and set the subject and session settings.
   > This repository doesn't include any protocols. See
   > [PuffyPenguin](https://github.com/musallGroup/PuffyPenguin) for an example multisensory
   > paradigm, or supply your own via Bpod's `Protocols` folder.
4. Adjust the spout positions, then press **Give Water** to confirm reward delivery.
5. Place the animal into the setup and head-fix it.
6. Adjust the lick detection threshold if needed.
7. Toggle the run/pause button (top left of the Bpod GUI) from pause to run to start the session.
8. Press **Stop** once the experiment is done.

## Labcams installation

> **TODO(you):** The installer files this section references (zipped `labcams-main` repository,
> the FLIR camera driver `.whl`, the SpinnakerSDK installer, and a starter `default.json`) are not
> included in this repository. Either add them somewhere in this repo and update the steps below
> to point at them, or leave this as an external pointer — decide and remove this note. Sources:
> [github.com/jcouto/labcams](https://github.com/jcouto/labcams) and the SpinnakerSDK/camera
> driver from FLIR/Teledyne directly.

You may follow the instructions at the [labcams repository](https://github.com/jcouto/labcams), or
follow these steps:

1. Install [Anaconda](https://conda.io/anaconda.html) if not already done, and add conda to the
   system PATH when asked during installation.
2. Obtain the labcams repository, the FLIR camera driver Python wheel
   (`spinnaker_python-2.5.0.80-cp38-cp38-win_amd64.whl`), the SpinnakerSDK installer
   (`SpinnakerSDK_FULL_2.5.0.80_x64.exe`), and a `default.json` file (see note above).
3. Download [Notepad++](https://notepad-plus-plus.org/downloads/v8.3.3/).
4. In the Anaconda prompt, create a new virtual environment called `labcams` with a downgraded
   3.8.12 version of Python:
   ```
   conda create -n labcams python=3.8 anaconda
   conda activate labcams
   ```
5. Open the labcams repository folder in Anaconda: `cd labcams-main`
6. Install the downgraded version of the PyQt package: `pip install PyQT5`
7. Install the remaining labcams requirements: `pip install -r requirements.txt`
8. Install the labcams software: `python setup.py develop`
9. Install SpinnakerSDK.
10. Install the camera driver: `pip install spinnaker_python-2.5.0.80-cp38-cp38-win_amd64.whl`
11. Generate the `default.json` file: `labcams`
12. Edit the `default.json` file (e.g. add the camera serial number) or copy and paste your own.
    Note: labcams only uses the filename `default.json`.
13. Install ffmpeg (only if you are capturing video): `conda install -c conda-forge ffmpeg`

To run labcams in the future, activate the labcams virtual environment first in the Anaconda
prompt (`conda activate labcams`) and then run `labcams`. Alternatively, add
`c:/users/YOURUSER/Anaconda3/envs/Scripts` and `bin` to the environment PATH on Windows.

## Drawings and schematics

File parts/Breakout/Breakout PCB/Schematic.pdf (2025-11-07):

Ethernet1- Motors | Ethernet2 - Wheel, Touch, 12V | Ethernet3 - Photodiodes, 5V | Ethernet4 - Speaker / Trigger

## right

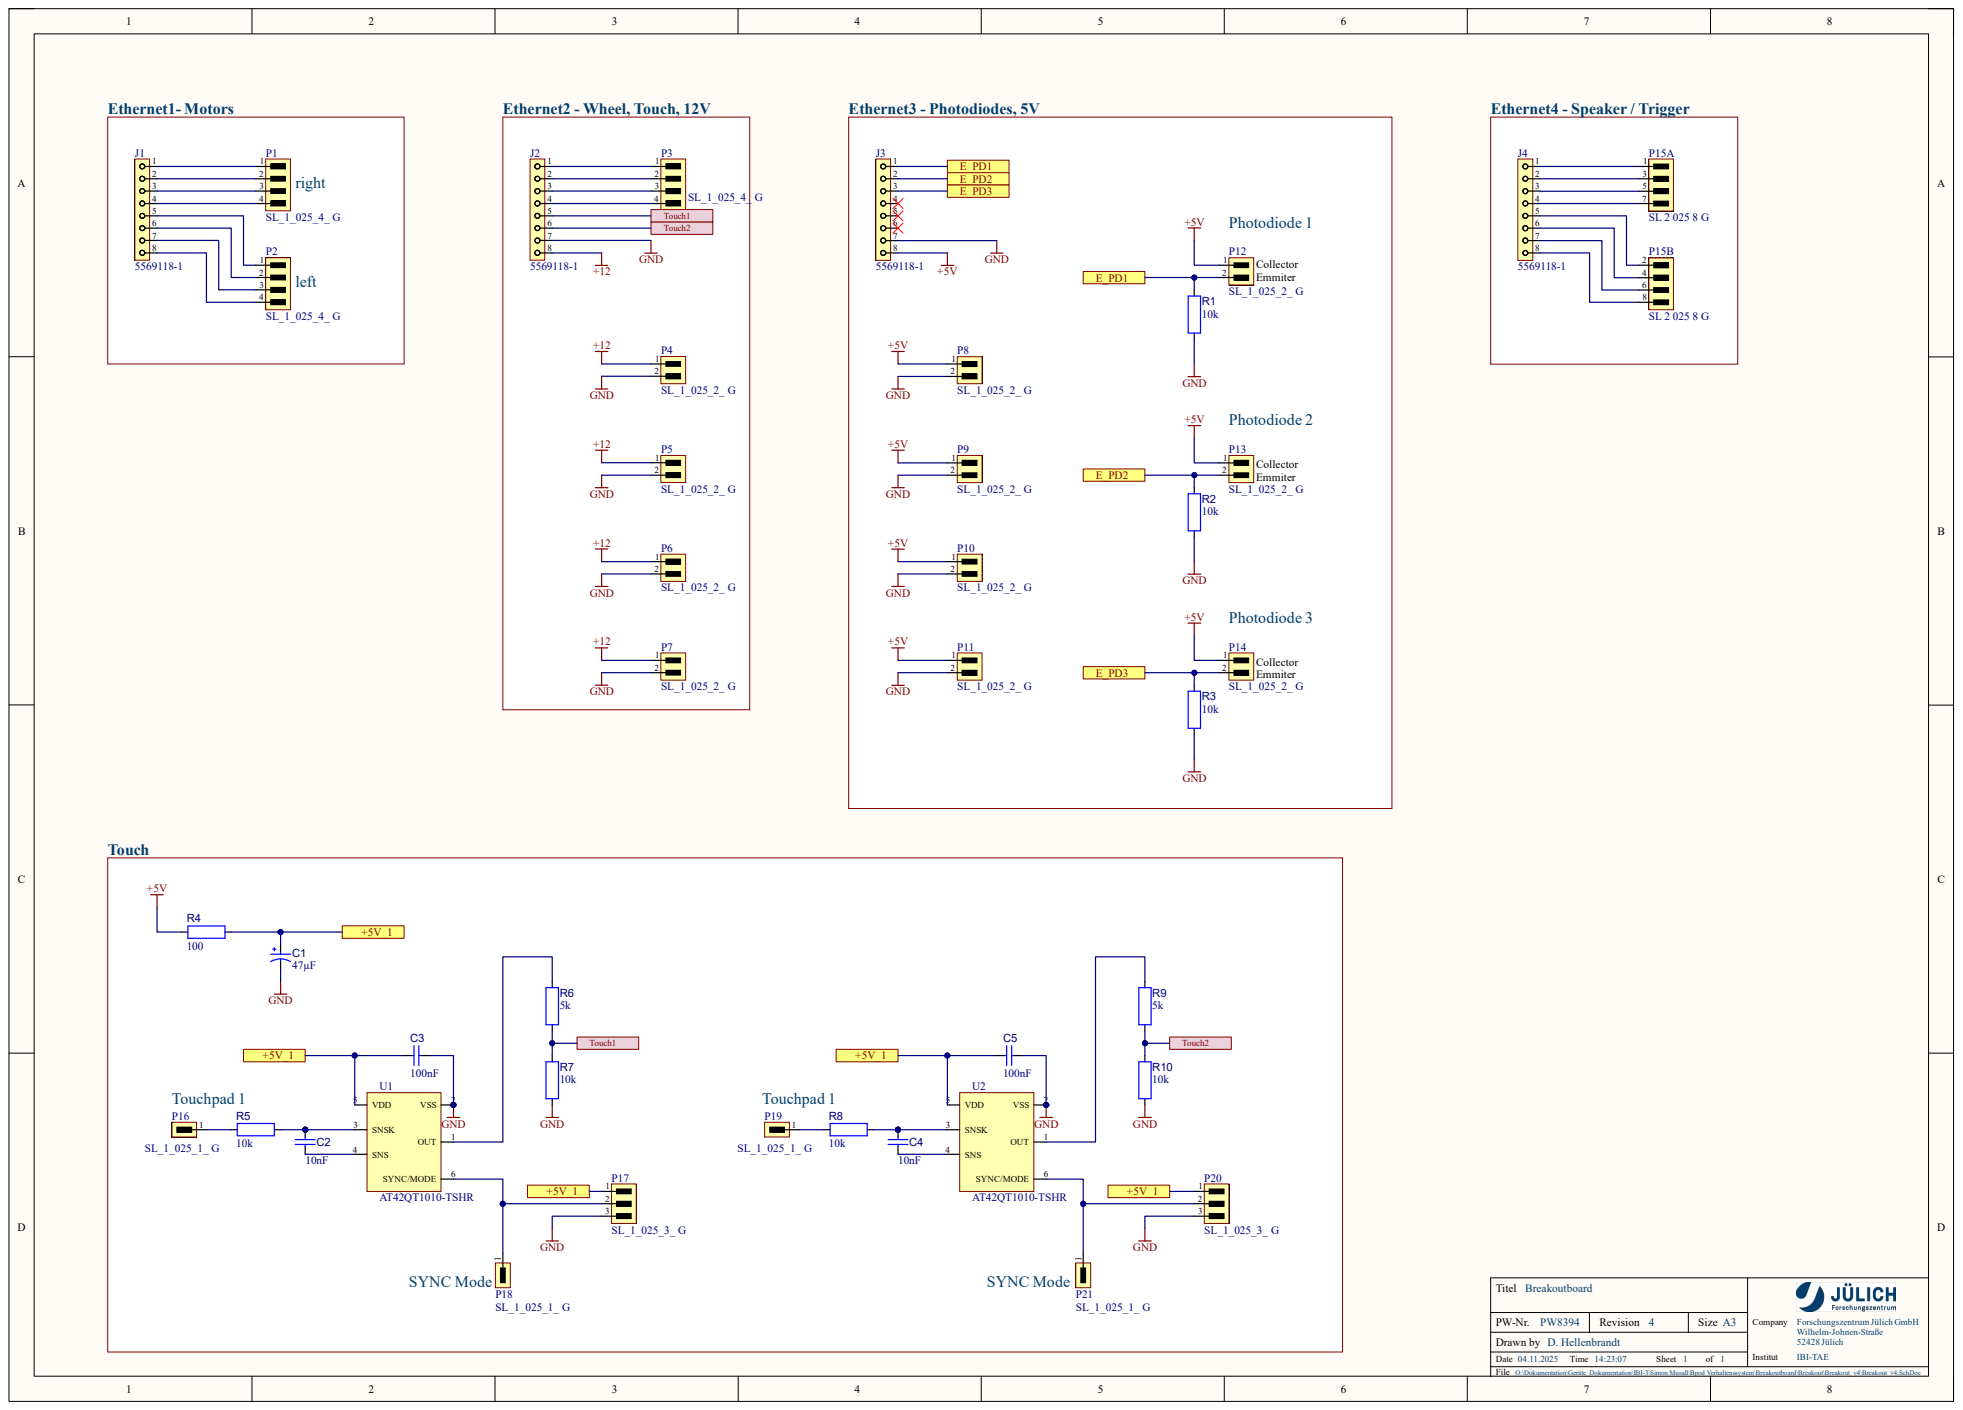
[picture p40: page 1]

O:\Dokumentation\Geräte_Dokumentation\IBI-3\Simon Musall\Bpod Verhaltenssystem\Breakoutboard\Breakout\Breakout_v4\Breakout_v4.SchDoc

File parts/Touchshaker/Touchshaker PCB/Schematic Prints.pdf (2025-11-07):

# Power input connectors Power output connectors

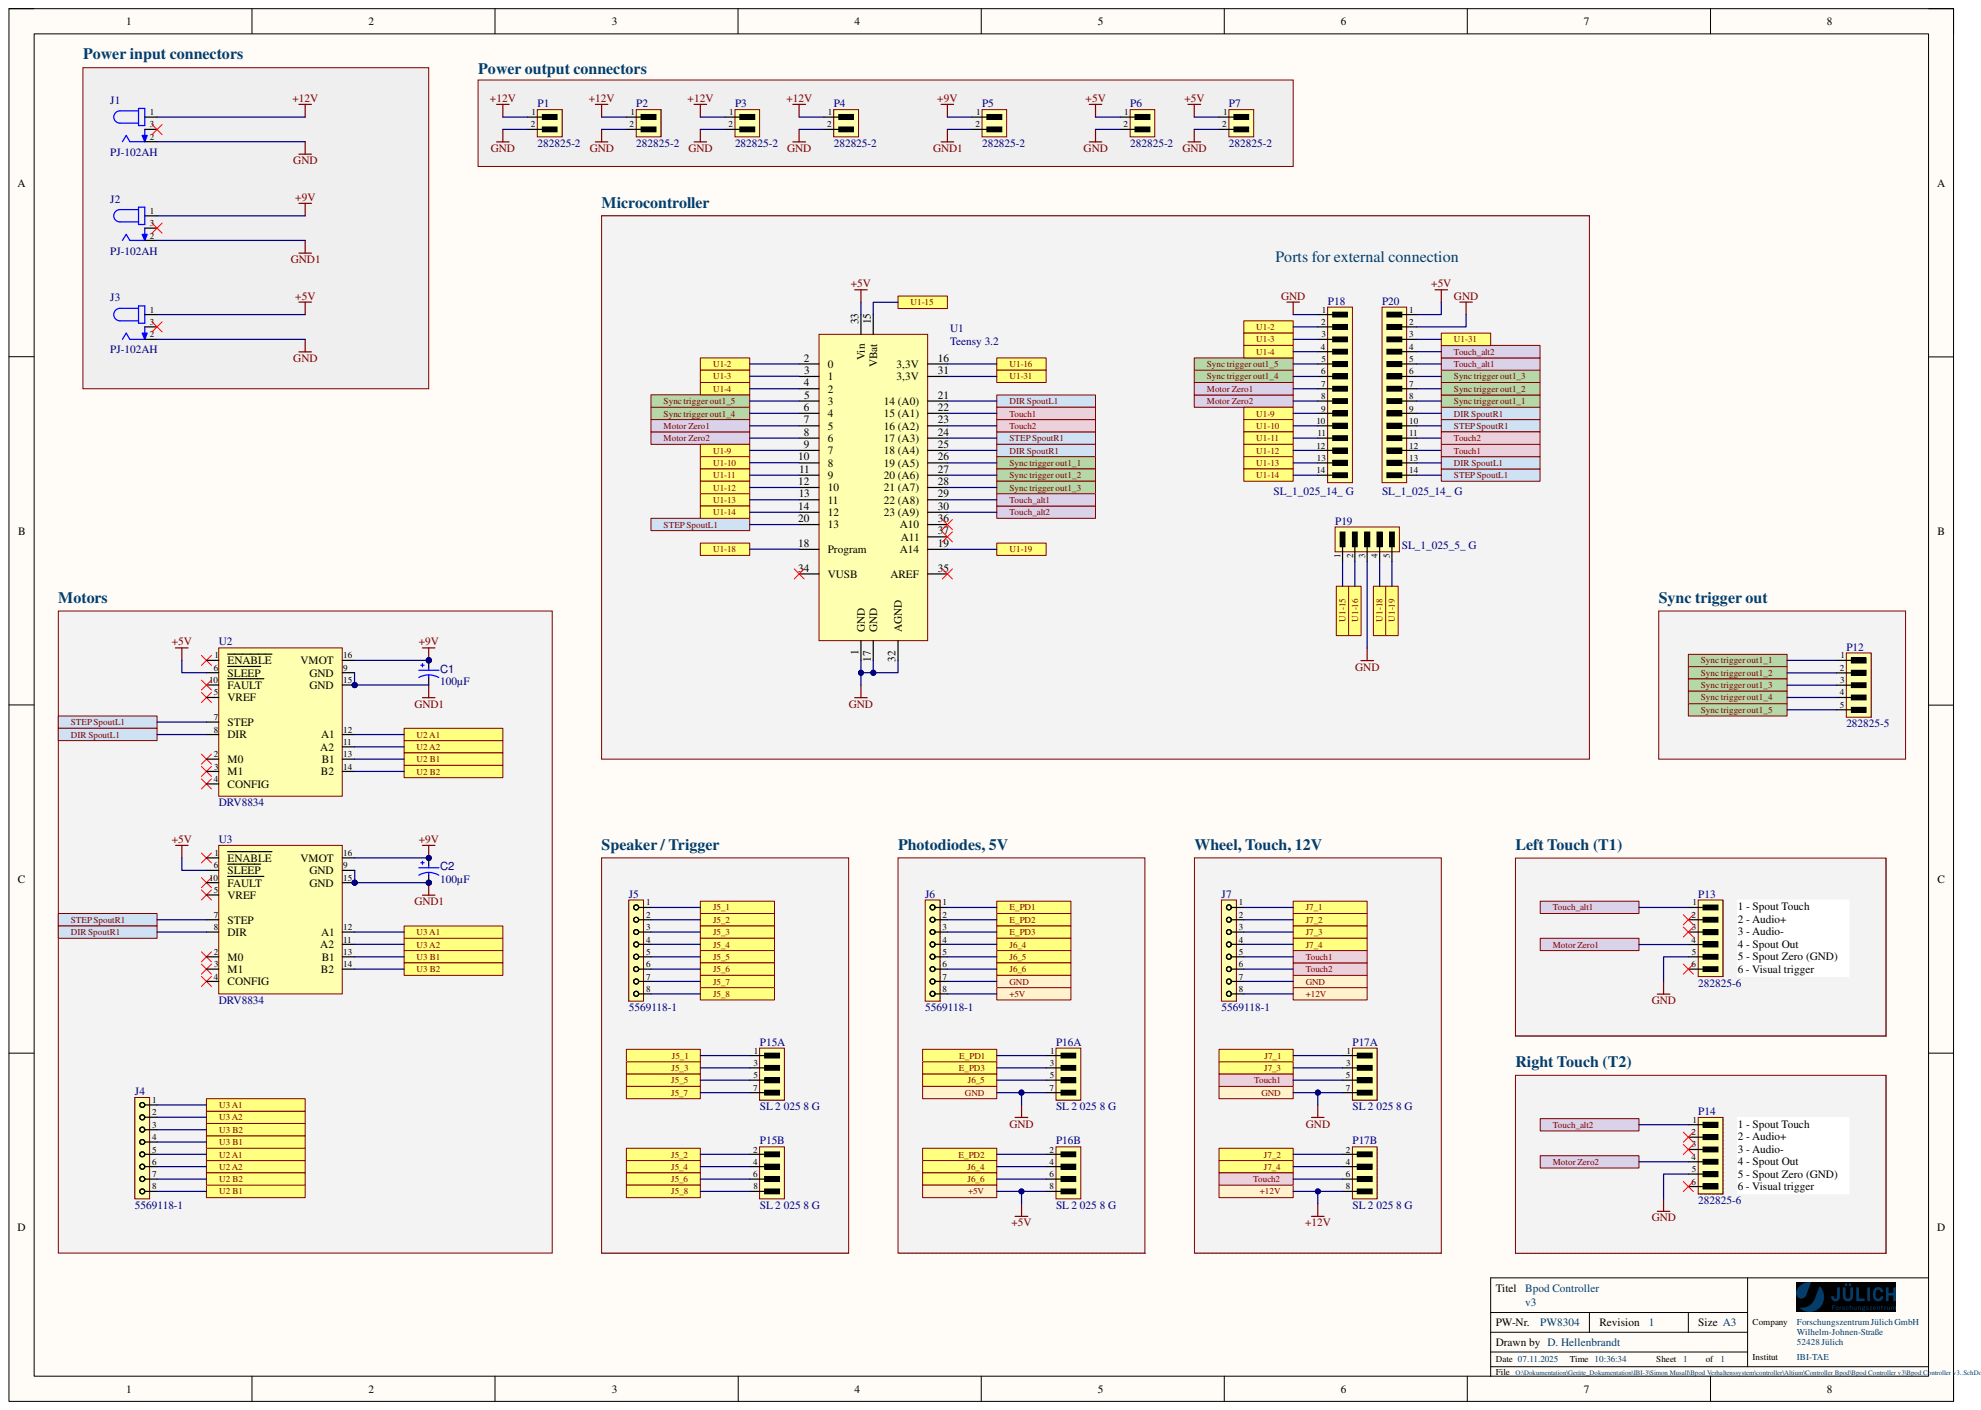
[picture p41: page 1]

Ports for external connection

O:\Dokumentation\Geräte_Dokumentation\IBI-3\Simon Musall\Bpod Verhaltenssystem\controller\Altium\Controller Bpod\Bpod Controller v3\Bpod Controller v3..SchDoc

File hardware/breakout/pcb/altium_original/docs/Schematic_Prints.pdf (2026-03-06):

Ethernet1- Motors | Ethernet2 - Wheel, Touch, 12V | Ethernet3 - Photodiodes, 5V | Ethernet4 - Speaker / Trigger

## right

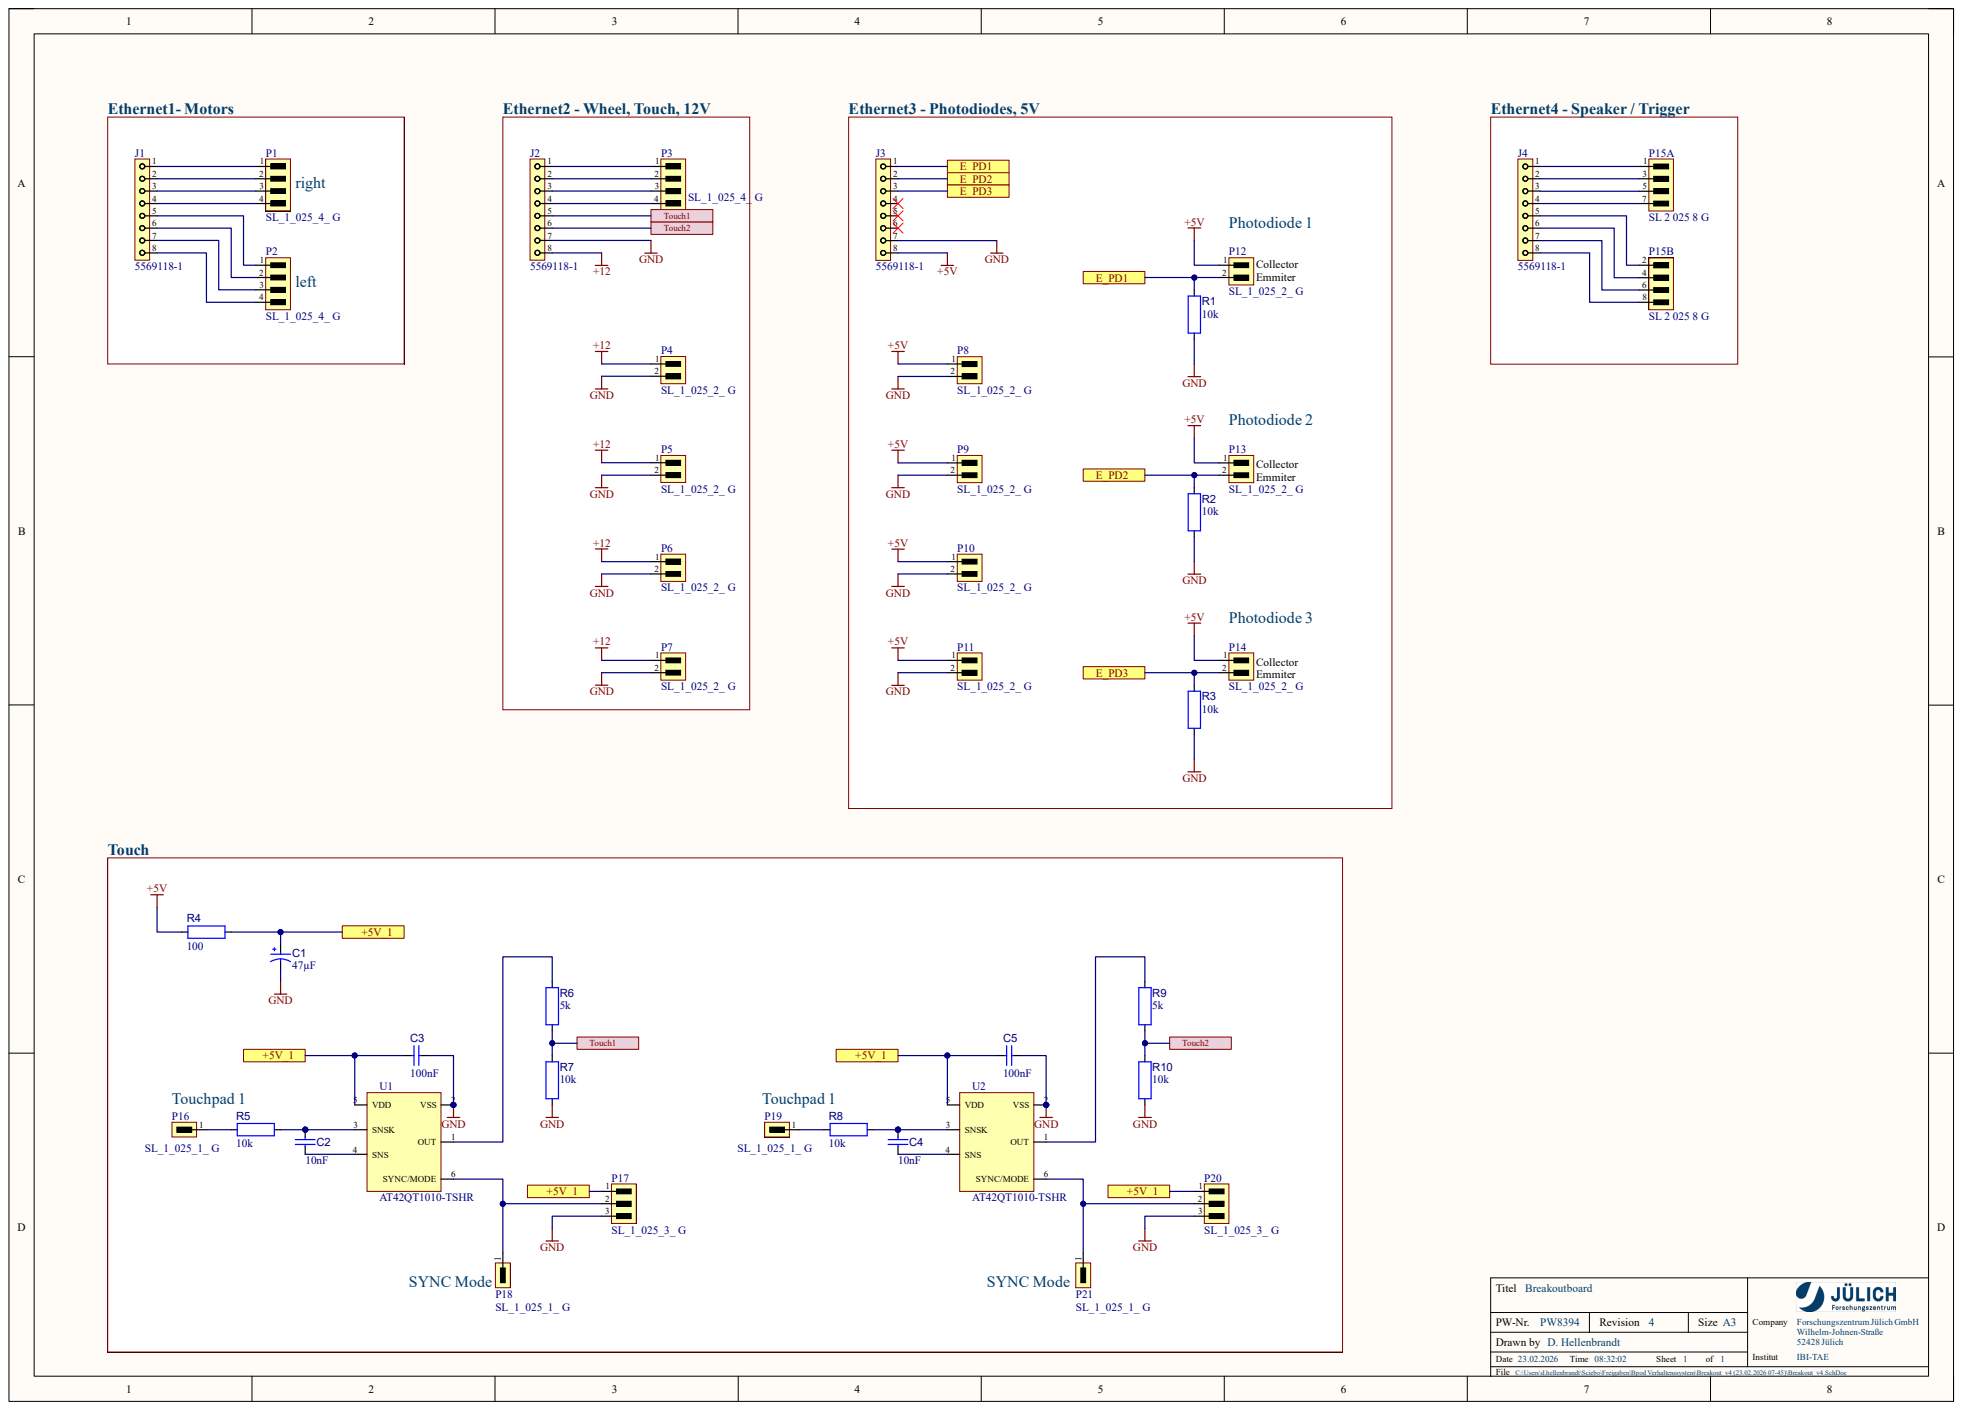
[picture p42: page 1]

C:\Users\d.hellenbrandt\Sciebo\Freigaben\Bpod Verhaltenssystem\Breakout_v4 (23.02.2026 07-45)\Breakout_v4.SchDoc

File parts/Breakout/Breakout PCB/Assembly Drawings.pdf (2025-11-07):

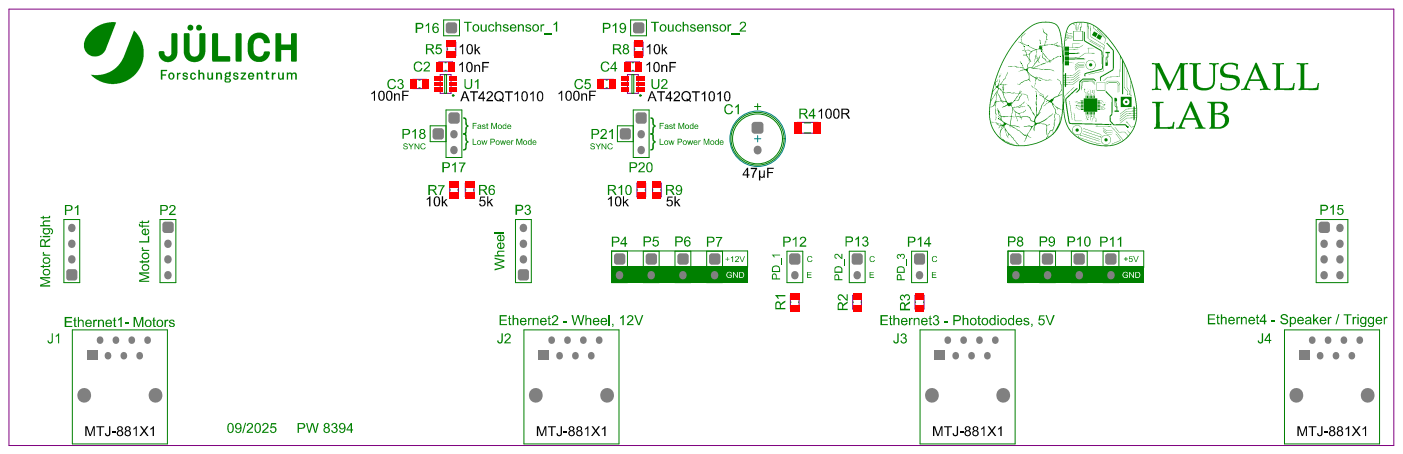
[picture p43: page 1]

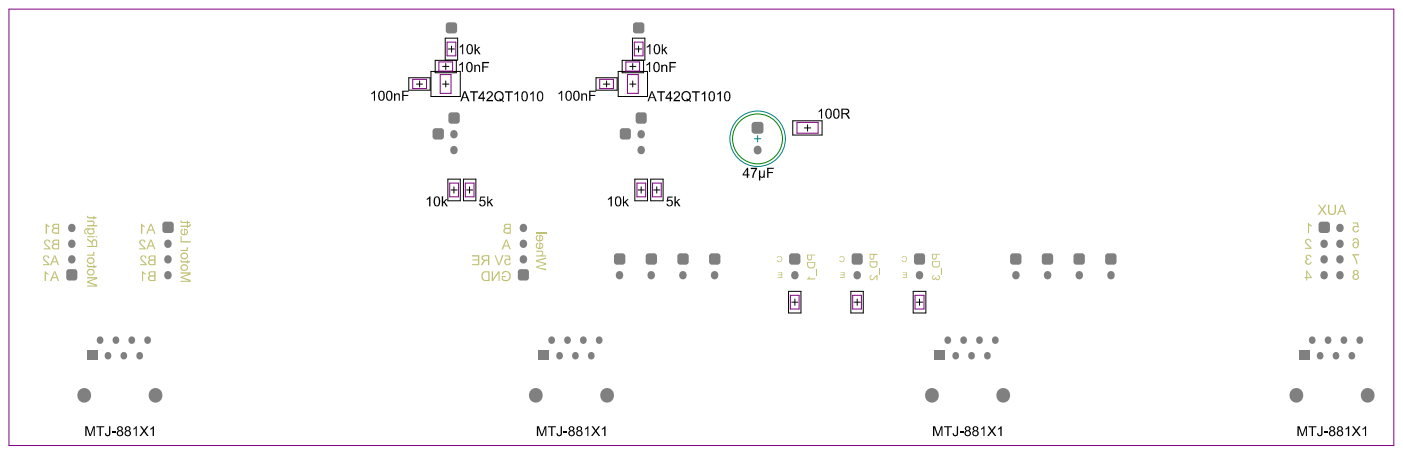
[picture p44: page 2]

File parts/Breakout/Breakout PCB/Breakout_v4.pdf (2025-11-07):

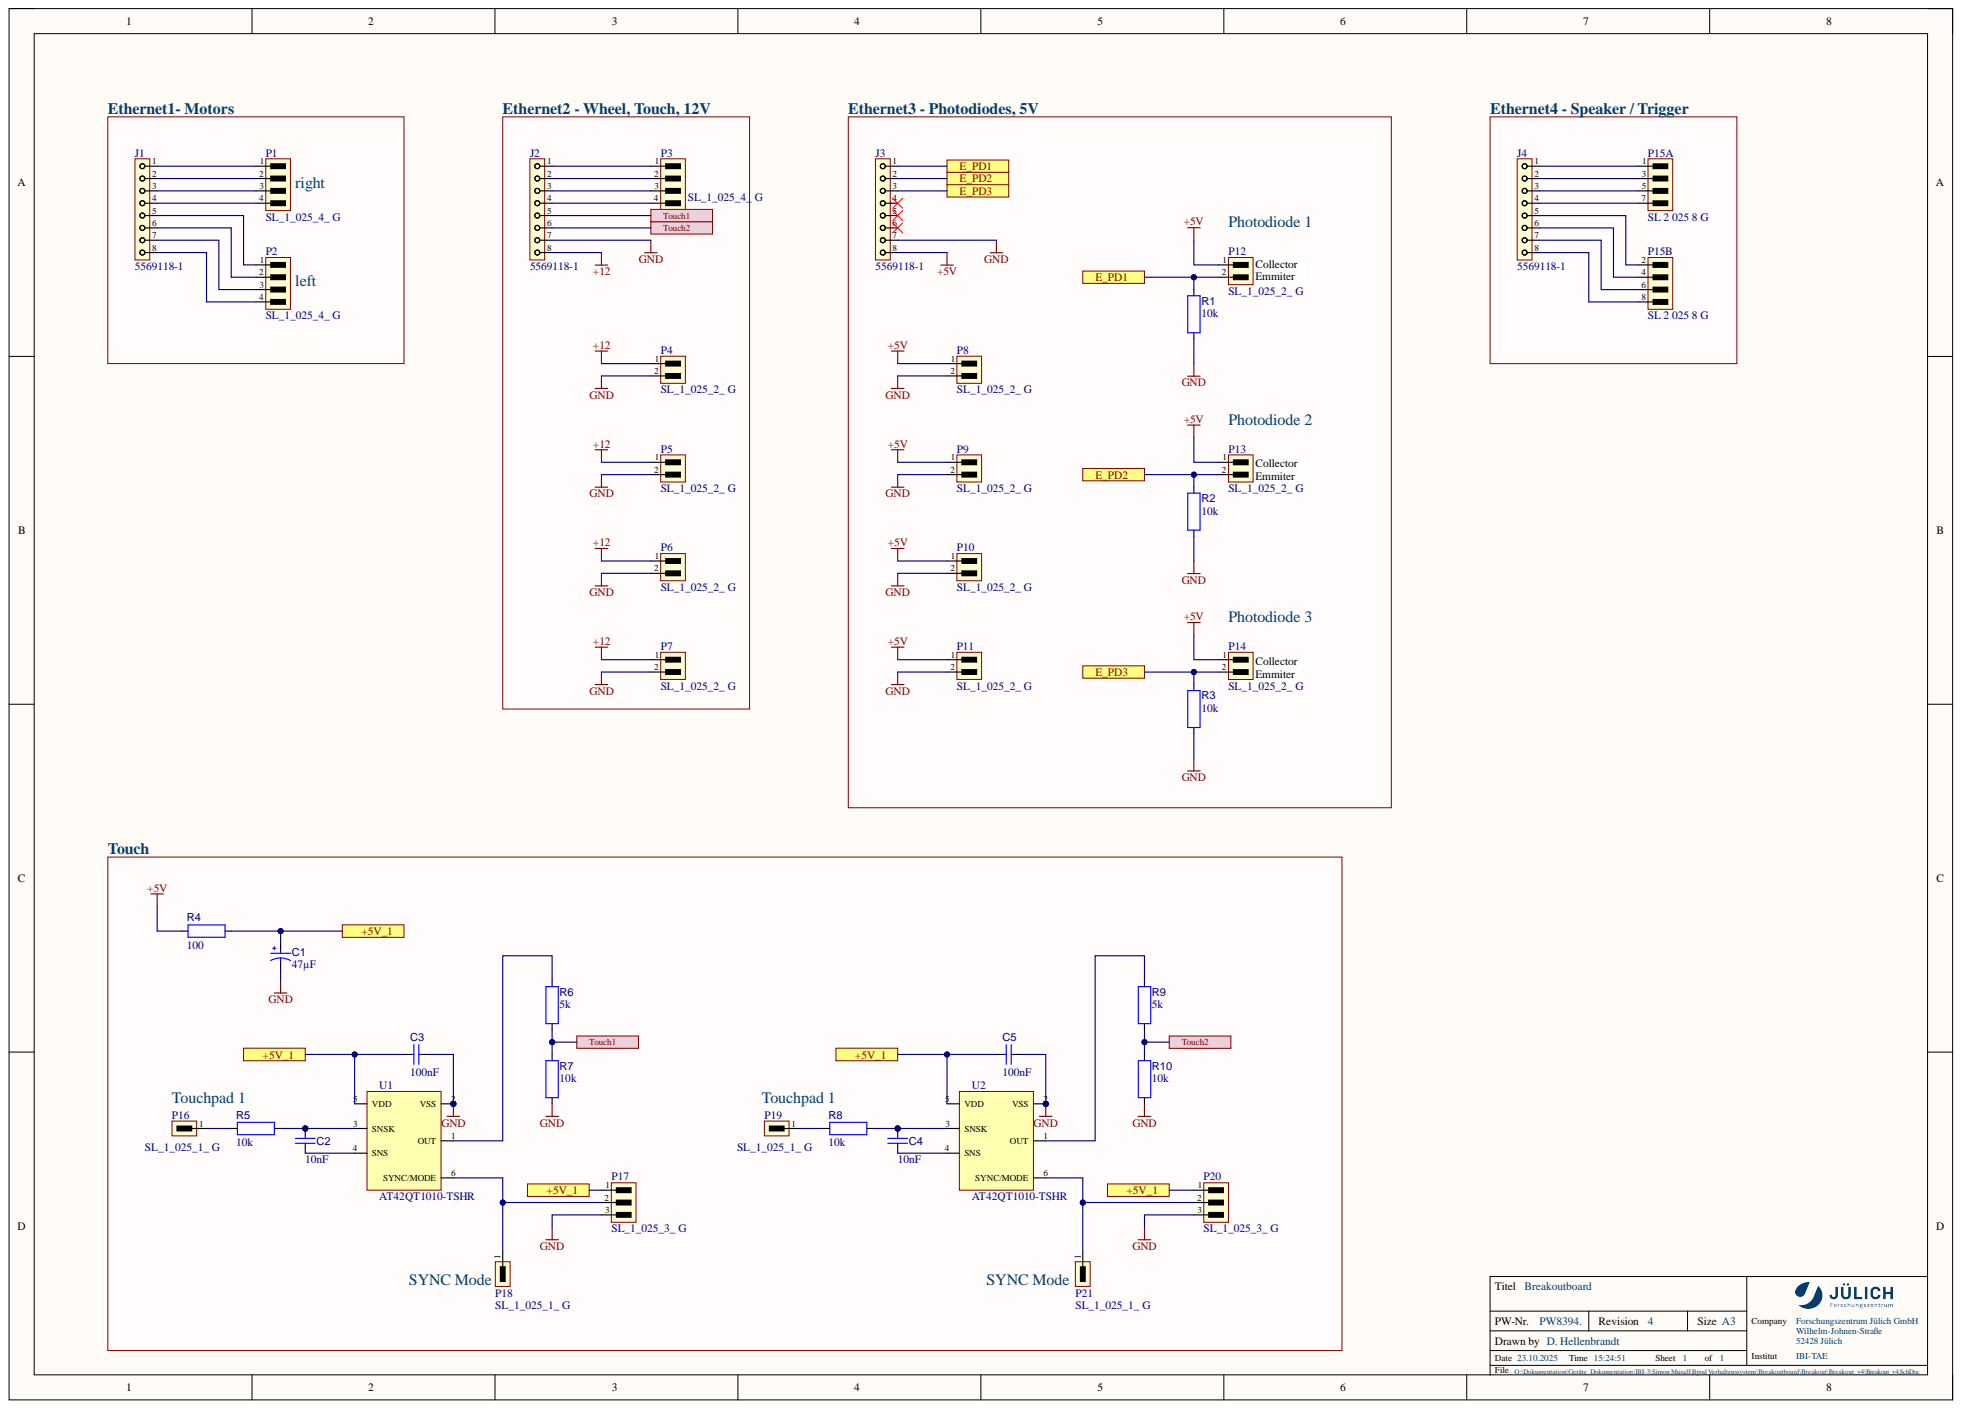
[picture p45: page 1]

O:\Dokumentation\Geräte_Dokumentation\IBI-3\Simon Musall\Bpod Verhaltenssystem\Breakoutboard\Breakout\Breakout_v4\Breakout_v4.SchDoc

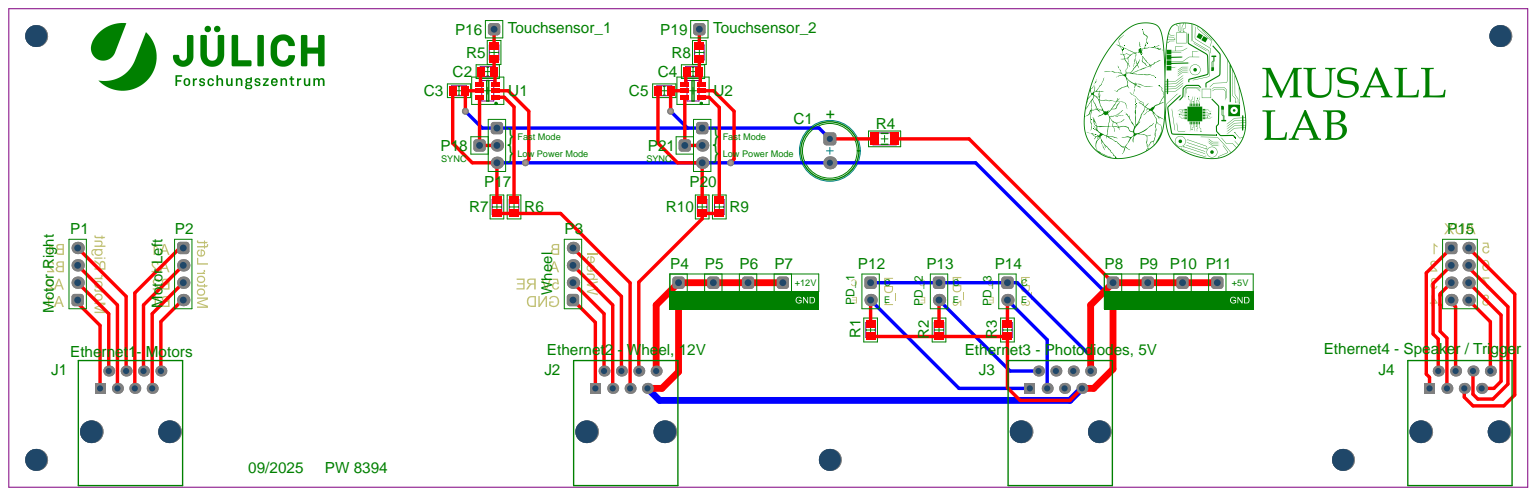
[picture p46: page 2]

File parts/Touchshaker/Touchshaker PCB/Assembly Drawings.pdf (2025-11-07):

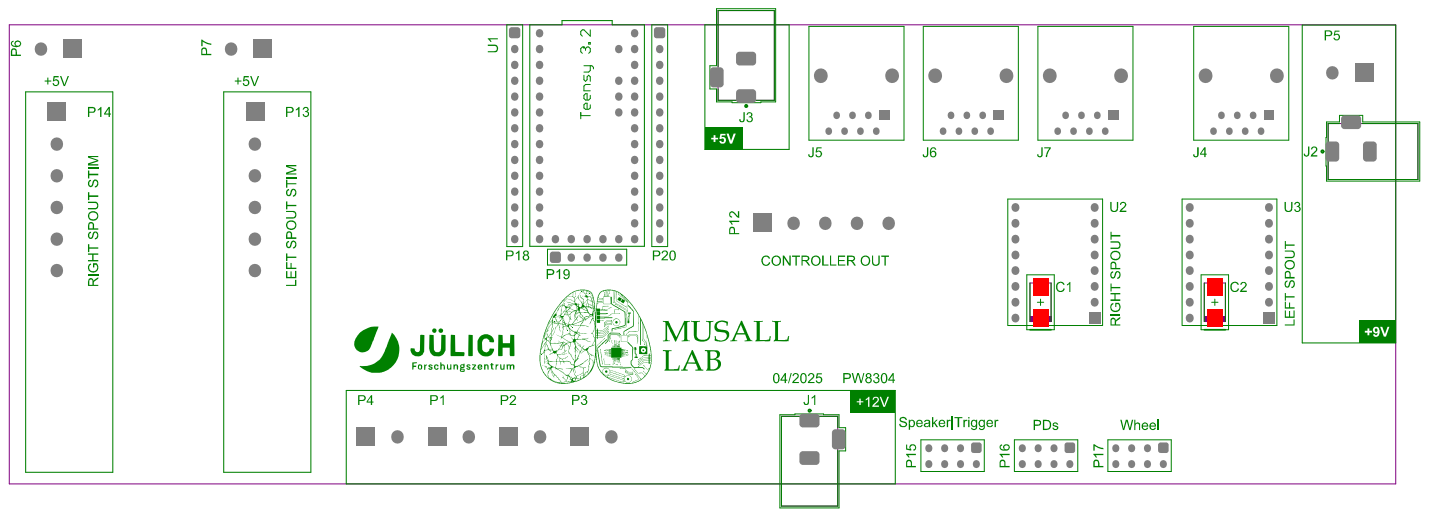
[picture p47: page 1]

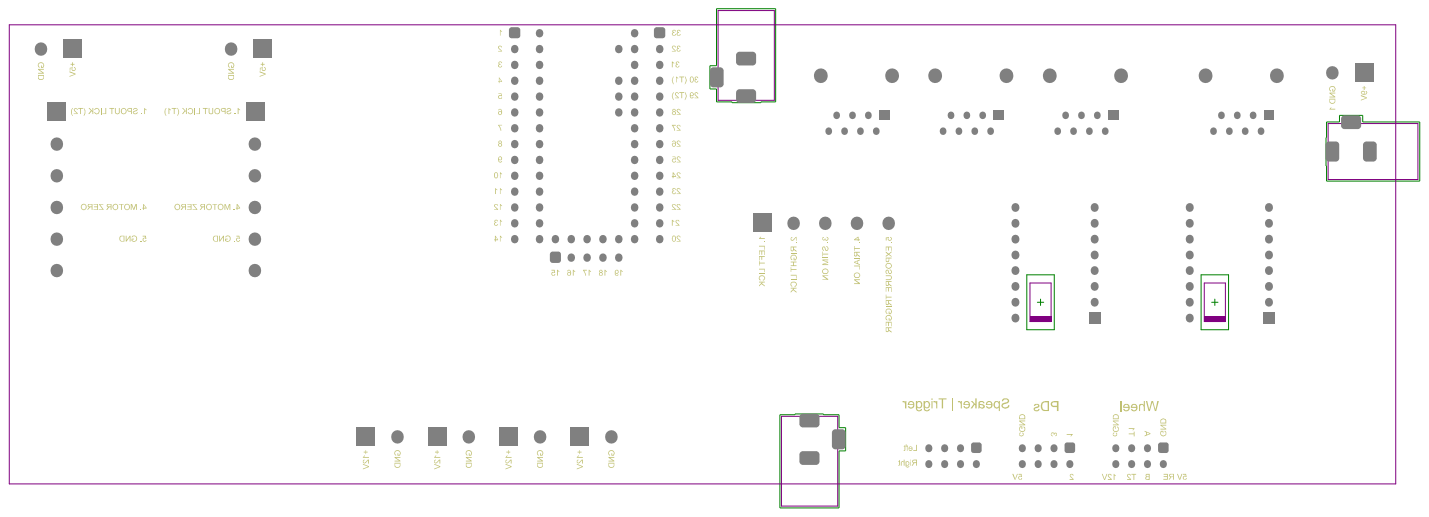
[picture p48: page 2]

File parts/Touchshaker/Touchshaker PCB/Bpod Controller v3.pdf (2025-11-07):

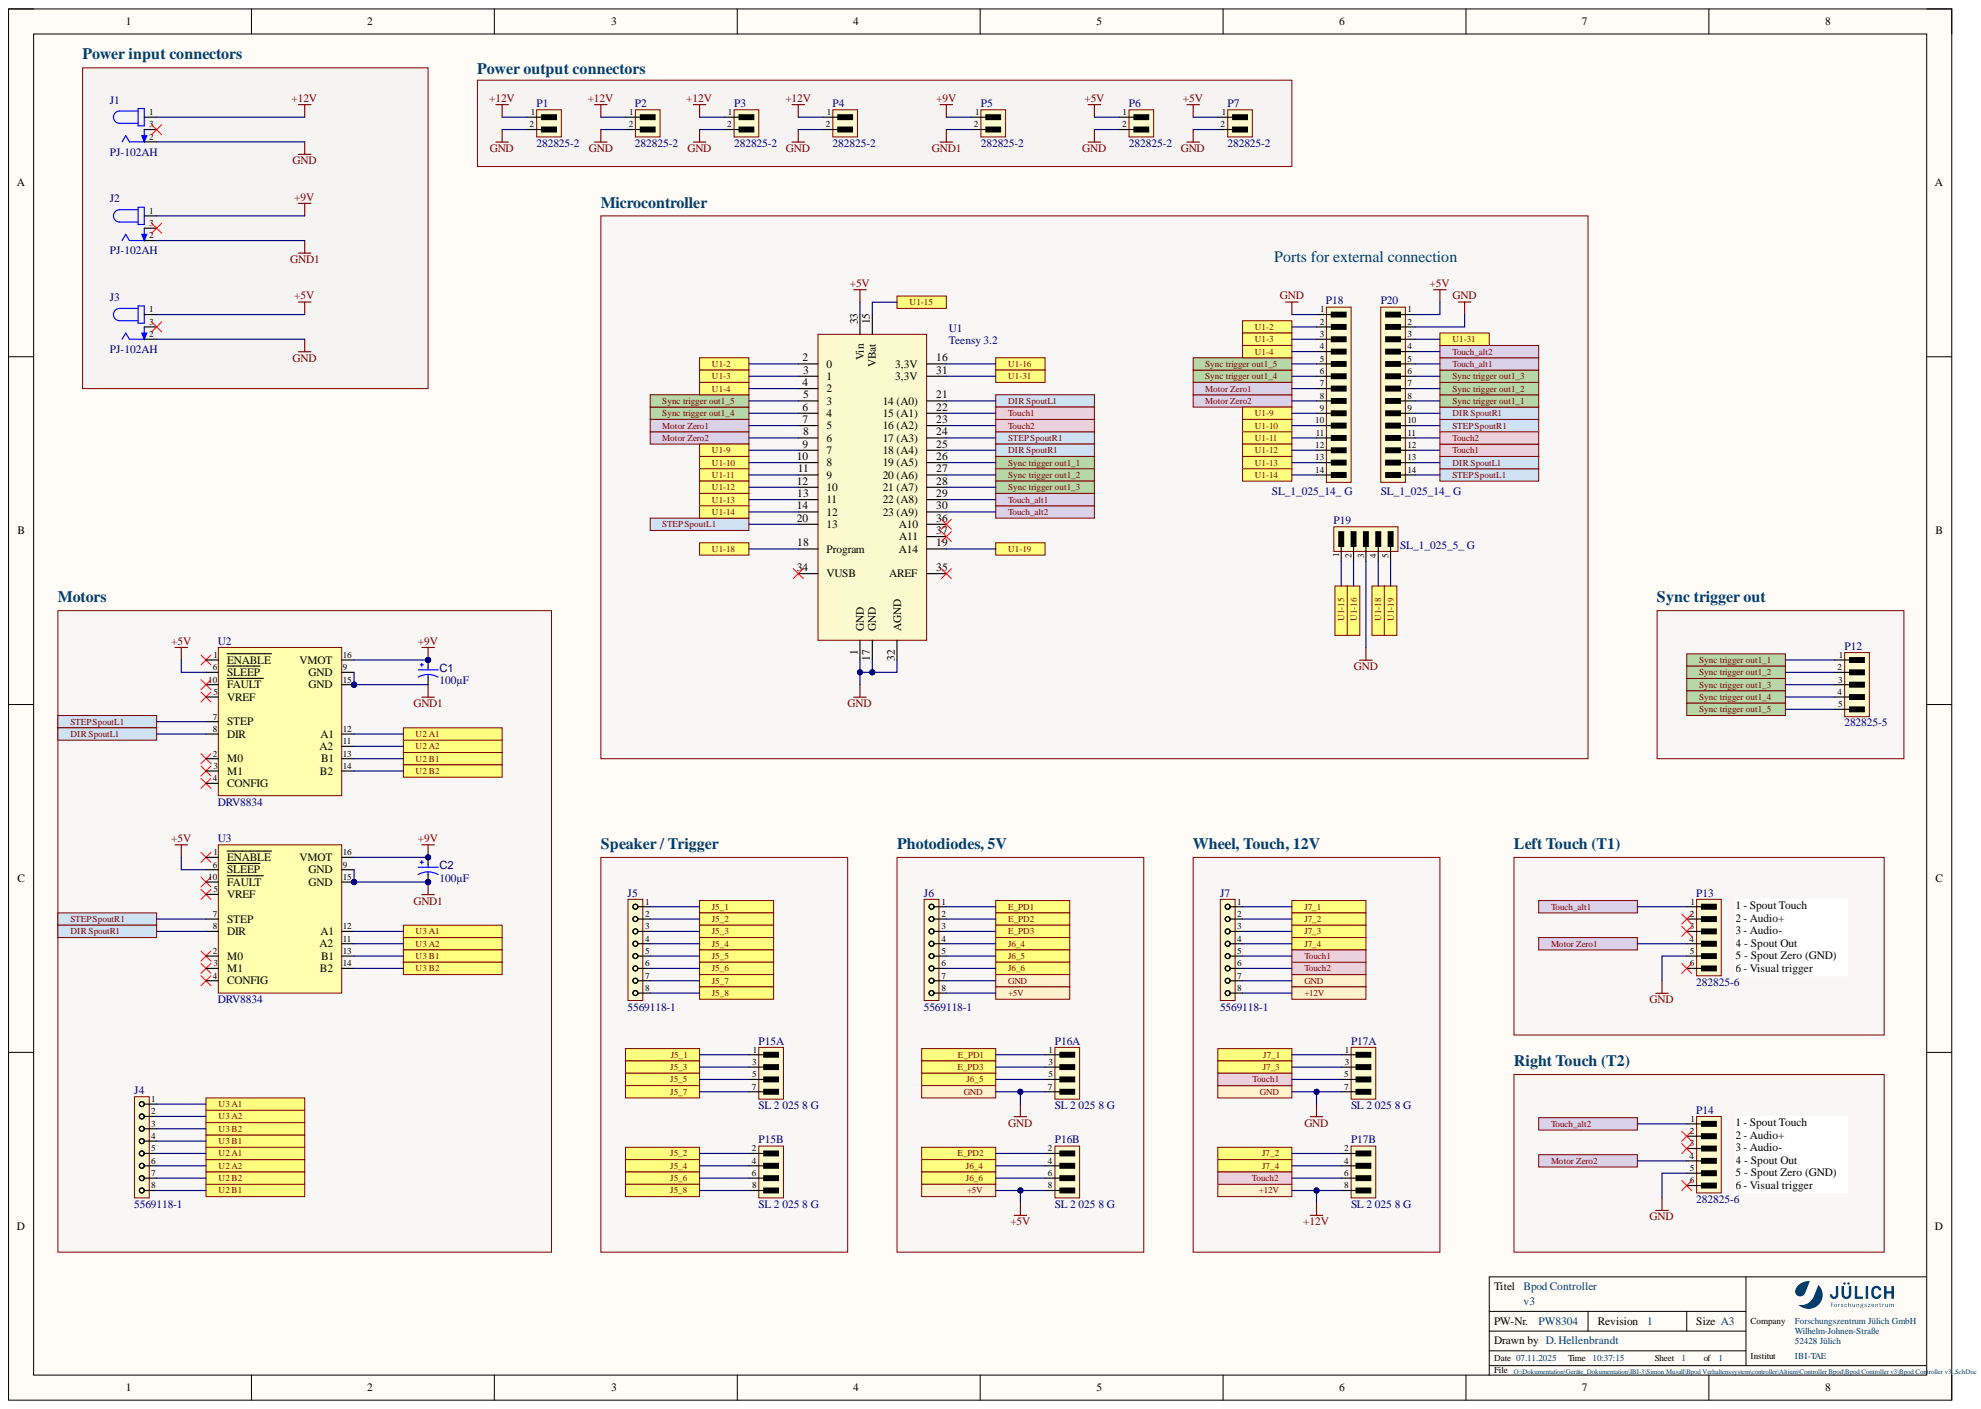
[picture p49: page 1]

Ports for external connection

Sync trigger out1_2 | 2
Sync trigger out1_3 | 3

O:\Dokumentation\Geräte_Dokumentation\IBI-3\Simon Musall\Bpod Verhaltenssystem\controller\Altium\Controller Bpod\Bpod Controller v3\Bpod Controller v3..SchDoc

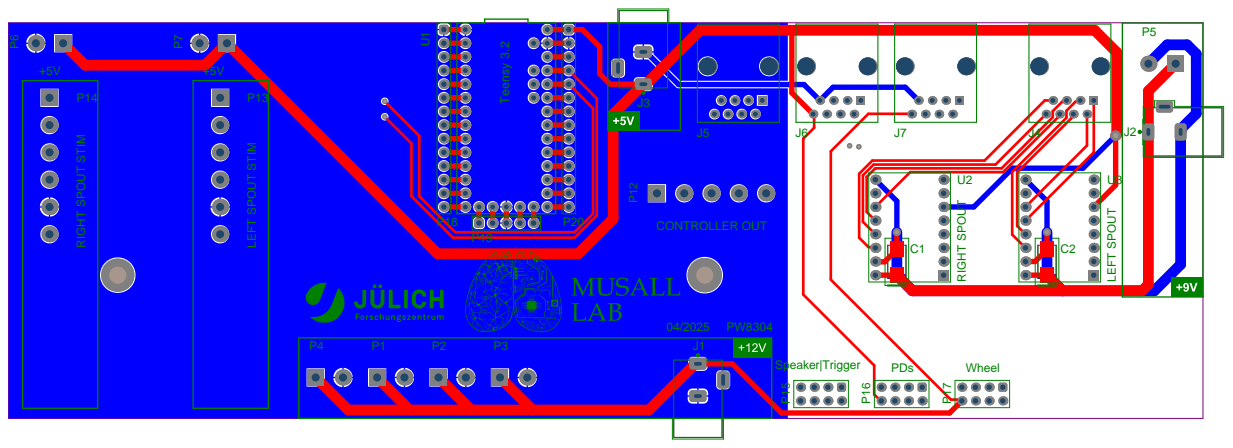
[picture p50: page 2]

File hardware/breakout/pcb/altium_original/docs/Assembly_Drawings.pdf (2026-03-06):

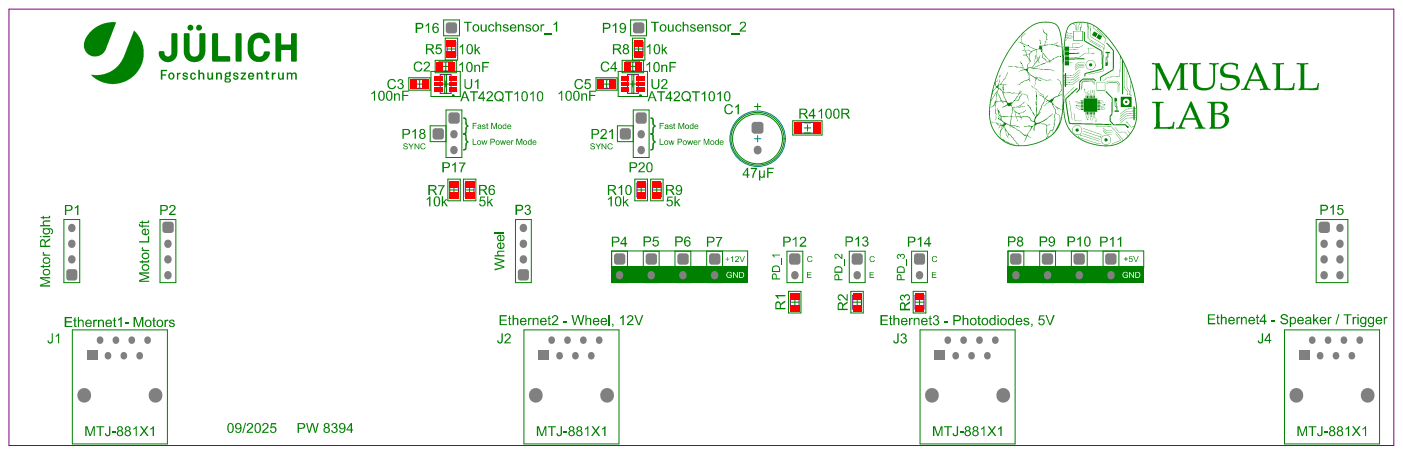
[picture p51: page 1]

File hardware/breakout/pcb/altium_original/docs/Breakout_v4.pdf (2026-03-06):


C:\Users\d.hellenbrandt\Sciebo\Freigaben\Bpod Verhaltenssystem\Breakout_v4 (23.02.2026 07-45)\Breakout_v4.SchDoc



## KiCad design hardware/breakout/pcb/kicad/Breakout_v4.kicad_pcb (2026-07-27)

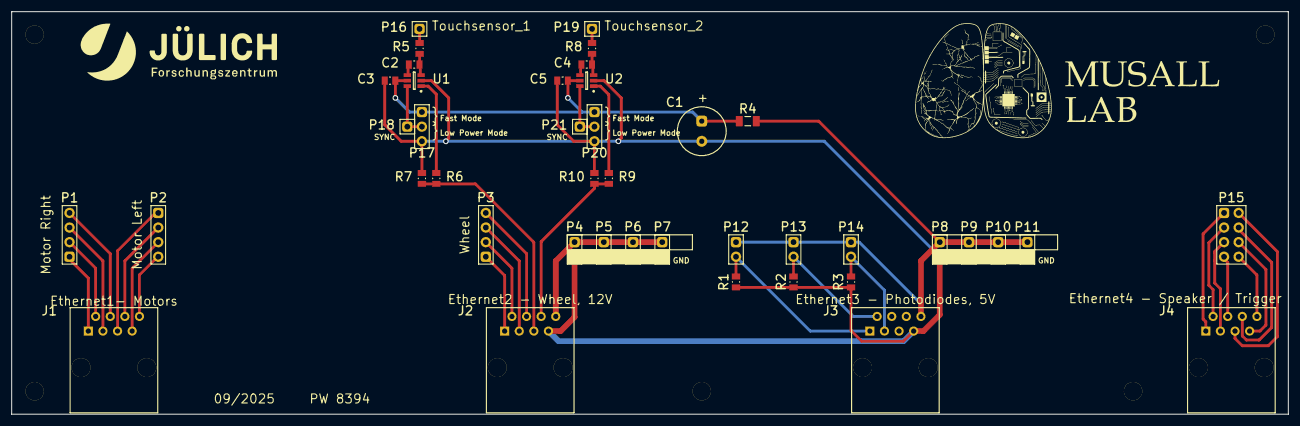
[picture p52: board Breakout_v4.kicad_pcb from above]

Board: 2 copper layers, 222.0 x 70.0 mm, 42 parts (0 on the bottom side), 39 nets.

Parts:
C1: 870585774003; WCAP-HTAH_D8H11.5
C2, C4: 10nF 0805 X7R 50V 5%; Copy of 0805
C3, C5: 100nF 0805 X7R 100V; 0805
J1, J2, J3, J4: 5569118-1; 5569118-1-Footprint-1
P1, P2, P3: SL_1_025_4_ G
P4, P5, P6, P7, P8, P9, P10, P11, P12, P13, P14: SL_1_025_2_ G
P15: SL 2 025 8 G; SL 2 025 2 G-Footprint-1
P16, P18, P19, P21: SL_1_025_1_ G; Copy of SL_1_025_2_ G
P17, P20: SL_1_025_3_ G; Copy of SL_1_025_4_ G
R1, R2, R3, R5, R7, R8, R10: 10K 0805 200V 0,25W 0,5% 50ppm/K; 0805 (2012)
R4: 100R 1206 200V 0,25W 25ppm/K; 1206 (3216)
R6, R9: 5K 0805 100V 0,2W; 0805 (2012)
U1, U2: AT42QT1010-TSHR; 6ST1_M

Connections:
+5V: J3.8, P8.1, P9.1, P10.1, P11.1, P12.1, P13.1, P14.1, R4.2
+12: J2.8, P4.1, P5.1, P6.1, P7.1
GND: C1.2, C3.2, C5.2, J2.7, J3.7, P4.2, P5.2, P6.2, P7.2, P8.2, P9.2, P10.2, P11.2, P17.3, P20.3, R1.1, R2.1, R3.1, R7.1, R10.1, U1.2, U2.2
NetC1_1: C1.1, C3.1, C5.1, P17.1, P20.1, R4.1, U1.5, U2.5
NetC2_1: C2.1, U1.4
NetC2_2: C2.2, R5.2, U1.3
NetC4_1: C4.1, U2.4
NetC4_2: C4.2, R8.2, U2.3
NetJ1_1: J1.1, P1.1
NetJ1_2: J1.2, P1.2
NetJ1_3: J1.3, P1.3
NetJ1_4: J1.4, P1.4
NetJ1_5: J1.5, P2.1
NetJ1_6: J1.6, P2.2
NetJ1_7: J1.7, P2.3
NetJ1_8: J1.8, P2.4
NetJ2_1: J2.1, P3.1
NetJ2_2: J2.2, P3.2
NetJ2_3: J2.3, P3.3
NetJ2_4: J2.4, P3.4
NetJ2_5: J2.5, R6.1, R7.2
NetJ2_6: J2.6, R9.1, R10.2
NetJ3_1: J3.1, P12.2, R1.2
NetJ3_2: J3.2, P13.2, R2.2
NetJ3_3: J3.3, P14.2, R3.2
NetJ4_1: J4.1, P15.1
NetJ4_2: J4.2, P15.3
NetJ4_3: J4.3, P15.5
NetJ4_4: J4.4, P15.7
NetJ4_5: J4.5, P15.2
NetJ4_6: J4.6, P15.4
NetJ4_7: J4.7, P15.6
NetJ4_8: J4.8, P15.8
NetP16_1: P16.1, R5.1
NetP17_2: P17.2, P18.1, U1.6
NetP19_1: P19.1, R8.1
NetP20_2: P20.2, P21.1, U2.6
NetR6_2: R6.2, U1.1
NetR9_2: R9.2, U2.1

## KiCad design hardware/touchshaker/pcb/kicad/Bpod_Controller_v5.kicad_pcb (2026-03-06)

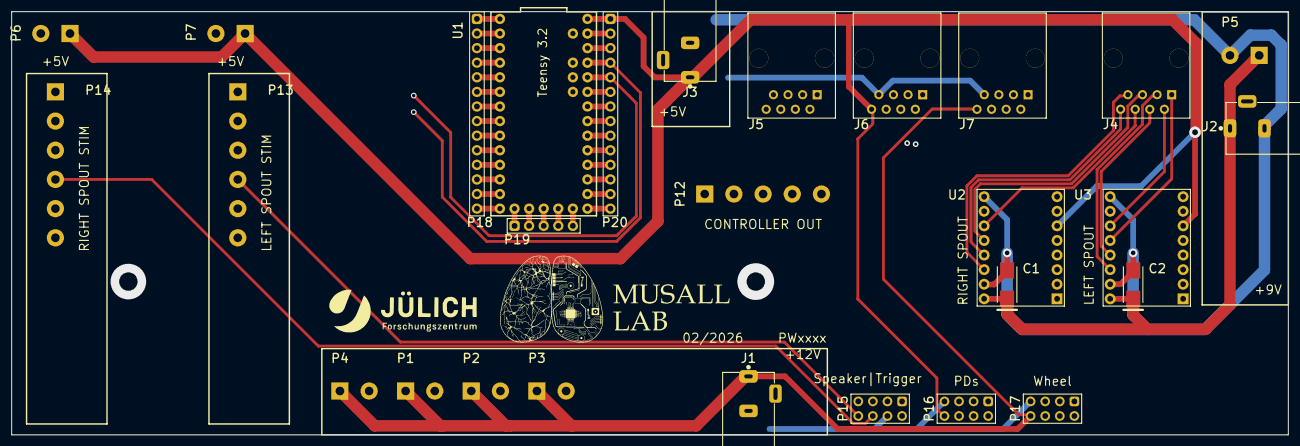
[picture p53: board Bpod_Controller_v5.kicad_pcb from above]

Board: 4 copper layers, 222.2 x 73.7 mm, 28 parts (0 on the bottom side), 56 nets.

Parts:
C1, C2: TAJC107K016RNJ; AVX-TAJ-C-2_M
J1, J2, J3: PJ-102AH; CUI_PJ-102AH
J4, J5, J6, J7: 5569118-1; 5569118-1-Footprint-1
P1, P2, P3, P4, P5, P6, P7: 282825-2; 282825-4-Footprint-1
P12: 282825-5; 282825-4-Footprint-1
P13, P14: 282825-6; 282825-4-Footprint-1
P15, P16, P17: SL 2 025 8 G; SL 2 025 2 G-Footprint-1
P18, P20: SL_1_025_14_ G
P19: SL_1_025_5_ G
U1: Teensy 3.2; New footprint 1
U2, U3: DRV8834; DRV8825 STEPPER MOTOR DRIVER CARRIER-Footprint-1

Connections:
+5V: J3.1, J6.8, P6.1, P7.1, P16.8, P20.1, U1.33, U2.6, U3.6
+9V: C1.1, C2.1, J2.1, P5.1, U2.16, U3.16
+12V: J1.1, J7.8, P1.1, P2.1, P3.1, P4.1, P17.8
GND: C1.2, C2.2, J1.2, J2.2, J3.2, J5.4, J6.7, J7.7, P1.2, P2.2, P3.2, P4.2, P5.2, P6.2, P7.2, P13.5, P14.5, P15.4, P16.7, P17.7, P18.1, P19.3, P20.2, U1.1, U1.17, U1.32, U2.9, U2.15, U3.9, U3.15
NetJ4_1: J4.1, U3.12
NetJ4_2: J4.2, U3.11
NetJ4_3: J4.3, U3.14
NetJ4_4: J4.4, U3.13
NetJ4_5: J4.5, U2.12
NetJ4_6: J4.6, U2.11
NetJ4_7: J4.7, U2.14
NetJ4_8: J4.8, U2.13
NetJ5_1: J5.1, P15.1
NetJ5_2: J5.2, P15.2
NetJ5_3: J5.3, P15.3
NetJ5_5: J5.5, P15.5
NetJ5_6: J5.6, P14.4, P15.6, P18.8, U1.8
NetJ5_7: J5.7, P15.7
NetJ5_8: J5.8, P13.4, P15.8, P18.7, U1.7
NetJ6_1: J6.1, P16.1
NetJ6_2: J6.2, P16.2
NetJ6_3: J6.3, P16.3
NetJ6_4: J6.4, P16.4
NetJ6_5: J6.5, P16.5
NetJ6_6: J6.6, P16.6
NetJ7_1: J7.1, P17.1
NetJ7_2: J7.2, P17.2
NetJ7_3: J7.3, P17.3
NetJ7_4: J7.4, P17.4
NetJ7_5: J7.5, P17.5, P20.12, U1.22
NetJ7_6: J7.6, P17.6, P20.11, U1.23
NetP12_1: P12.1, P20.8, U1.26
NetP12_2: P12.2, P20.7, U1.27
NetP12_3: P12.3, P20.6, U1.28
NetP12_4: P12.4, P18.6, U1.6
NetP12_5: P12.5, P18.5, U1.5
NetP13_1: P13.1, P20.5, U1.29
NetP14_1: P14.1, P20.4, U1.30
NetP18_2: P18.2, U1.2
NetP18_3: P18.3, U1.3
NetP18_4: P18.4, U1.4
NetP18_9: P18.9, U1.9
NetP18_10: P18.10, U1.10
NetP18_11: P18.11, U1.11
NetP18_12: P18.12, U1.12
NetP18_13: P18.13, U1.13
NetP18_14: P18.14, U1.14
NetP19_1: P19.1, U1.15
NetP19_2: P19.2, U1.16
NetP19_4: P19.4, U1.18
NetP19_5: P19.5, U1.19
NetP20_3: P20.3, U1.31
NetP20_9: P20.9, U1.25, U3.8
NetP20_10: P20.10, U1.24, U3.7
NetP20_13: P20.13, U1.21, U2.8
NetP20_14: P20.14, U1.20, U2.7

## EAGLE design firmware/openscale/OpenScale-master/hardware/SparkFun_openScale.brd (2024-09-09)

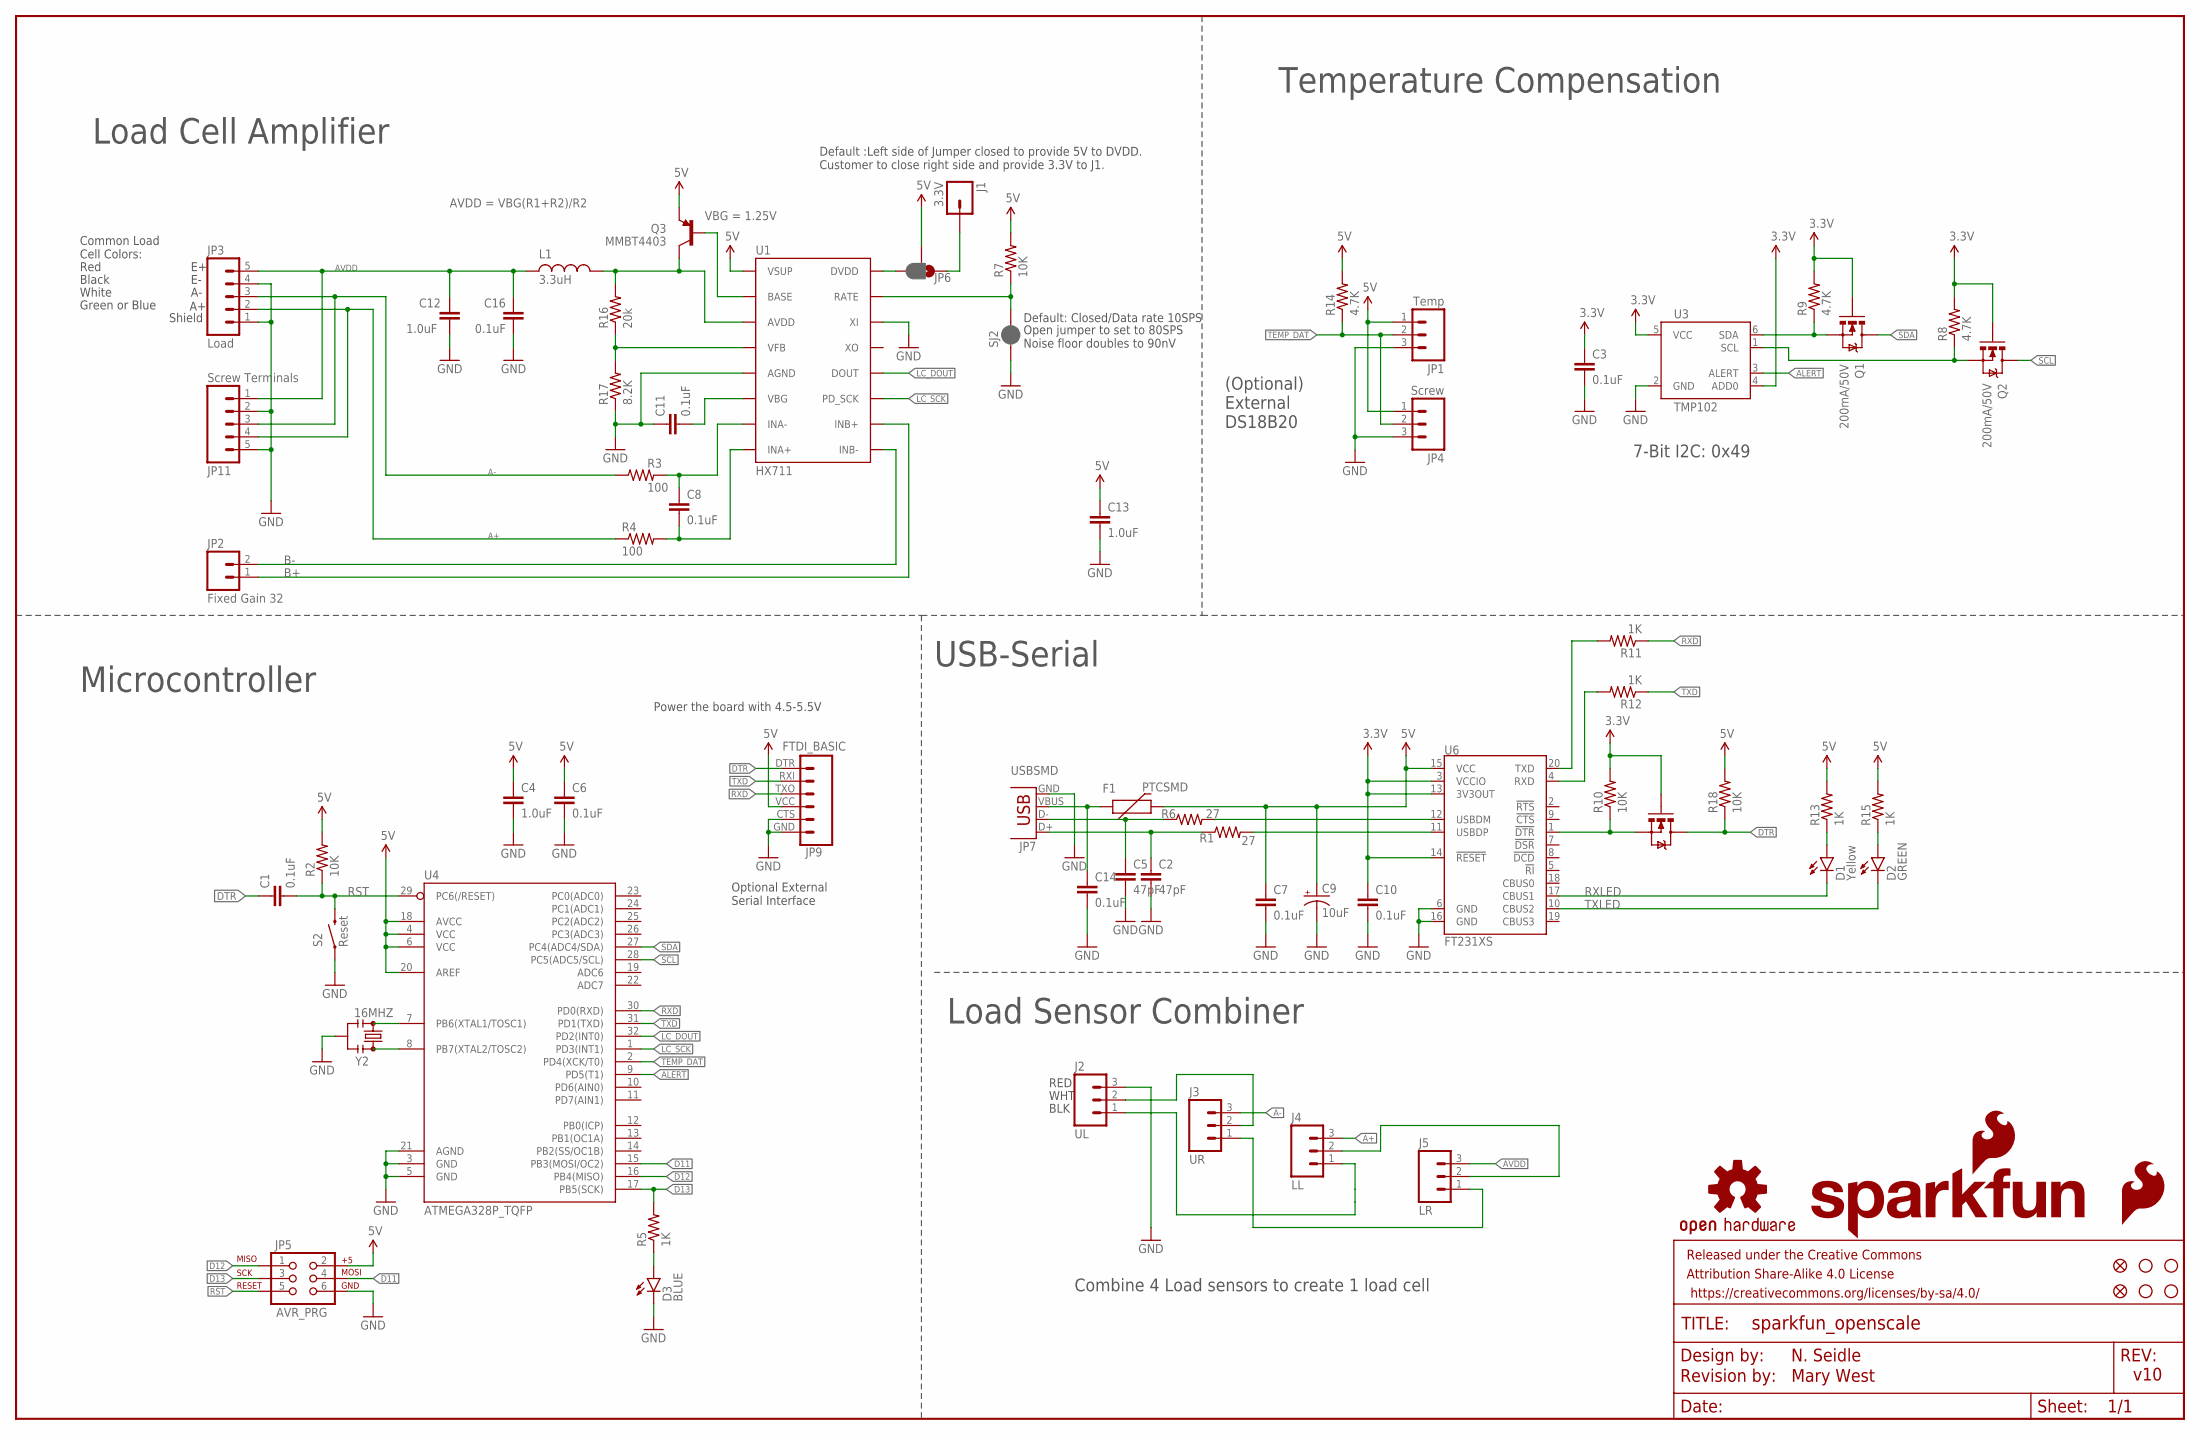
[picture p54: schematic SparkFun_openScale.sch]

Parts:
C1, C3, C6, C7, C8, C10, C11, C14, C16: 0.1uF; 0603-CAP
C2, C5: 47pF; 0603-CAP
C4, C12, C13: 1.0uF; 0603-CAP
C9: 10uF; EIA3216
D1: Yellow; LED-1206
D2: GREEN; LED-1206
D3: BLUE; LED-1206
F1: PTCSMD; PTC-1206
FID1, FID2: FIDUCIALUFIDUCIAL; MICRO-FIDUCIAL
FRAME1: FRAME-LEDGER; CREATIVE_COMMONS
J1: 3.3V; 1X01
J2: UL; 1X03
J3: UR; 1X03
J4: LL; 1X03
J5: LR; 1X03
JP1: Temp; 1X03_NO_SILK
JP2: Fixed Gain 32; 1X02
JP3: Load; 1X05_NO_SILK
JP4: Screw; SCREWTERMINAL-3.5MM-3_LOCK.007S
JP5: AVR_PRG; 2X3
JP6: JUMPER-PAD-3-2OF3_NC_BY_PASTE; PAD-JUMPER-3-2OF3_NC_BY_PASTE_YES_SILK_FULL_BOX
JP7: USBSMD; USB-MINIB
JP9: FTDI_BASIC
JP11: Screw Terminals; SCREWTERMINAL-3.5MM-5
L1: 3.3uH; 0805
LOGO2: OSHW-LOGOS; OSHW-LOGO-S
LOGO3: SFE_LOGO_FLAME.1_INCH; SFE_LOGO_FLAME_.1
LOGO4: SFE_LOGO_NAME_FLAME.1_INCH; SFE_LOGO_NAME_FLAME_.1
Q1, Q2: 200mA/50V; SOT23-3
Q3: MMBT4403; SOT23-3
Q4: MOSFET-NCHANNEL2N7002PW; SOT323
R1, R6: 27; 0603
R2, R7, R10, R18: 10K; 0603-RES
R3, R4: 100; 0603-RES
R5, R11, R12, R13, R15: 1K; 0603-RES
R8, R9, R14: 4.7K; 0603-RES
R16: 20k; 0603-RES
R17: 8.2K; 0603-RES
S2: Reset; TACTILE-SWITCH-SMD
SJ2: JUMPER-PAD-2-NC_BY_PASTE; PAD-JUMPER-2-NC_BY_PASTE_YES_SILK
STANDOFF1, STANDOFF2, STANDOFF3, STANDOFF4: STAND-OFF
U1: HX711; SO16
U3: TMP102; SOT563
U4: ATMEGA328P_TQFP; TQFP32-08
U6: FT231XS; SSOP20_L
Y2: 16MHZ; RESONATOR-SMD

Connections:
2: J4.2, J5.2
3.3V: C3.1, C10.1, Q1.1 (G), Q2.1 (G), Q4.1 (G), R8.2, R9.2, R10.2, U3.4 (ADD0), U3.5 (VCC), U6.3 (VCCIO), U6.13 (3V3OUT), U6.14 (!RESET)
5V: C4.1, C6.1, C7.1, C9.A (+), C13.1, F1.2, JP1.1, JP4.1, JP5.2, JP6.2, JP9.VCC (4), Q3.2 (E), R2.2, R7.2, R13.2, R14.2, R15.2, R18.2, U1.1 (VSUP), U4.4 (VCC), U4.6 (VCC), U4.18 (AVCC), U4.20 (AREF), U6.15 (VCC)
A+: J4.3, JP3.2, JP11.4, R4.1
A-: J3.3, JP3.3, JP11.3, R3.1
ALERT: U3.3 (ALERT), U4.9 (PD5(T1))
AVDD: C12.2, C16.1, J5.3, JP3.5, JP11.1, L1.1
B+: JP2.1, U1.10 (INB+)
B-: JP2.2, U1.9 (INB-)
D11: JP5.4, U4.15 (PB3(MOSI/OC2))
D12: JP5.1, U4.16 (PB4(MISO))
D13: JP5.3, R5.2, U4.17 (PB5(SCK))
DTR: C1.1, JP9.DTR (1), Q4.3 (D), R18.1
GND: C2.2, C3.2, C4.2, C5.2, C6.2, C7.2, C9.C (-), C10.2, C11.1, C12.1, C13.2, C14.2, C16.2, D3.C, J2.3, JP1.3, JP3.1, JP3.4, JP4.3, JP5.6, JP7.GND, JP9.CTS (5), JP9.GND (6), JP11.2, JP11.5, R17.1, S2.1, SJ2.1, U1.5 (AGND), U1.14 (XI), U3.2 (GND), U4.3 (GND), U4.5 (GND), U4.21 (AGND), U6.6 (GND), U6.16 (GND), Y2.2
LC_DOUT: U1.12 (DOUT), U4.32 (PD2(INT0))
LC_SCK: U1.11 (PD_SCK), U4.1 (PD3(INT1))
LV_SCL: Q2.2 (S), R8.1, U3.1 (SCL)
LV_SDA: Q1.2 (S), R9.1, U3.6 (SDA)
unnamed: U4.7 (PB6(XTAL1/TOSC1)), Y2.1
unnamed: D3.A, R5.1
unnamed: U4.8 (PB7(XTAL2/TOSC2)), Y2.3
unnamed: C5.1, JP7.D-, R6.1
unnamed: D1.A, R13.1
unnamed: D2.A, R15.1
unnamed: C2.1, JP7.D+, R1.1
unnamed: R6.2, U6.12 (USBDM)
unnamed: R7.1, SJ2.2, U1.15 (RATE)
unnamed: C8.1, R3.2, U1.7 (INA-)
unnamed: C8.2, R4.2, U1.8 (INA+)
unnamed: C14.1, F1.1, JP7.VBUS
unnamed: R1.2, U6.11 (USBDP)
unnamed: R12.2, U6.4 (RXD)
unnamed: JP6.3, U1.16 (DVDD)
unnamed: R11.2, U6.20 (TXD)
unnamed: Q3.1 (B), U1.2 (BASE)
unnamed: R16.1, R17.2, U1.4 (VFB)
unnamed: J1.1, JP6.1
unnamed: J2.2, J3.2
unnamed: C11.2, U1.6 (VBG)
unnamed: J2.1, J4.1
unnamed: J3.1, J5.1
unnamed: Q4.2 (S), R10.1, U6.1 (!DTR)
RIPUP@: L1.2, Q3.3 (C), R16.2, U1.3 (AVDD)
RST: C1.2, JP5.5, R2.1, S2.3 (2), U4.29 (PC6(/RESET))
RXD: JP9.TXO (3), R11.1, U4.30 (PD0(RXD))
RXLED: D1.C, U6.17 (CBUS1)
SCL: Q2.3 (D), U4.28 (PC5(ADC5/SCL))
SDA: Q1.3 (D), U4.27 (PC4(ADC4/SDA))
TEMP_DAT: JP1.2, JP4.2, R14.1, U4.2 (PD4(XCK/T0))
TXD: JP9.RXI (2), R12.1, U4.31 (PD1(TXD))
TXLED: D2.C, U6.10 (CBUS2)

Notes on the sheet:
Microcontroller
USB-Serial
Default: Closed/Data rate 10SPS
Open jumper to set to 80SPS Noise floor doubles to 90nV
Red
Black
White
Green or Blue
Common Load Cell Colors:
Temperature Compensation
(Optional) External DS18B20
Load Cell Amplifier
7-Bit I2C: 0x49
Shield
Optional External Serial Interface
VBG = 1.25V
AVDD = VBG(R1+R2)/R2
v10
N. Seidle
Power the board with 4.5-5.5V
RED
WHT
BLK
Combine 4 Load sensors to create 1 load cell
Load Sensor Combiner
Default :Left side of Jumper closed to provide 5V to DVDD. Customer to close right side and provide 3.3V to J1.
Revision by: Mary West

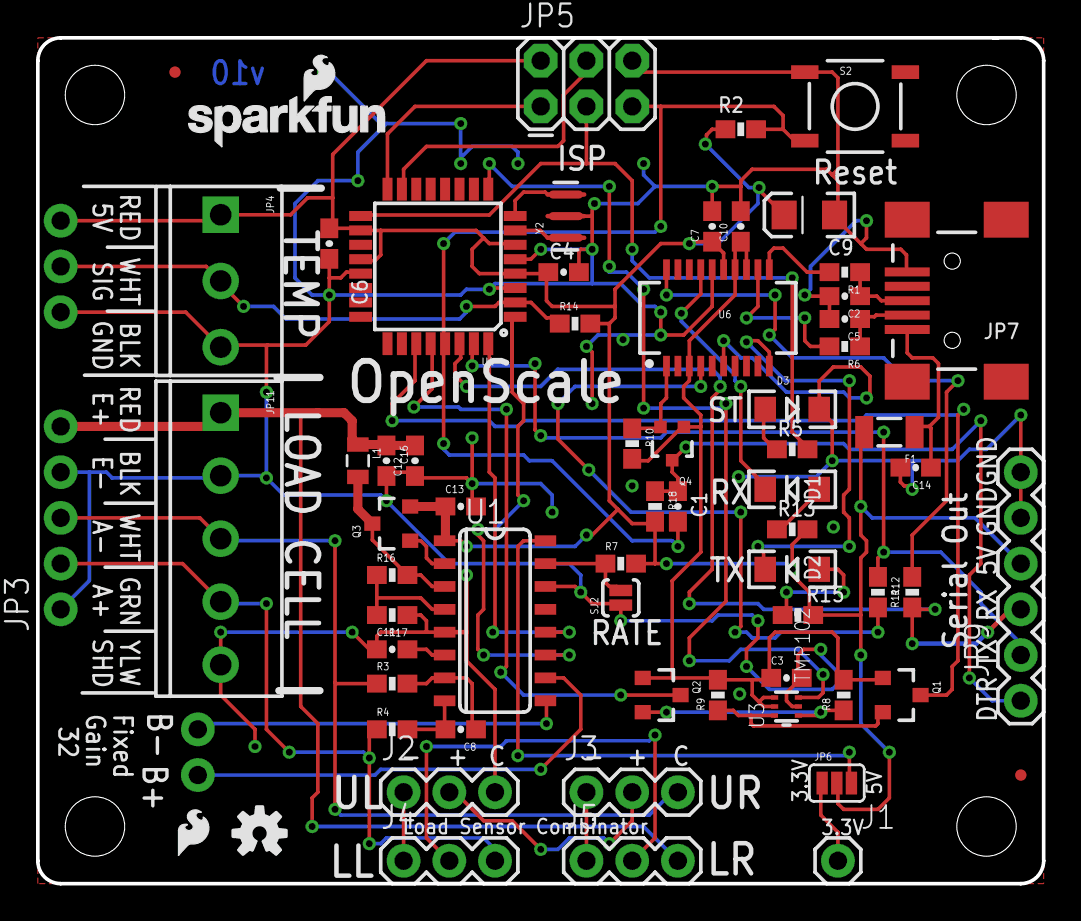
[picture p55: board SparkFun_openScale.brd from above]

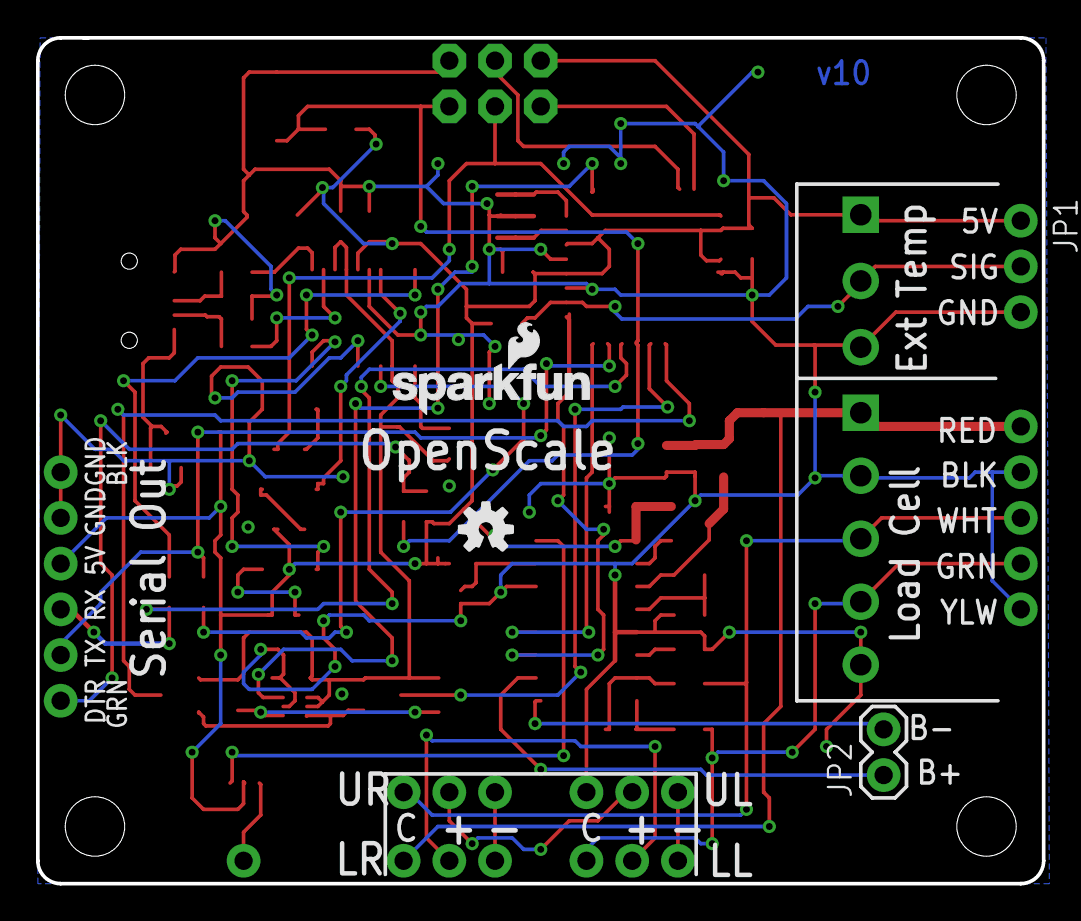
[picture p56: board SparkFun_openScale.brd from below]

Board: 2 copper layers, 55.9 x 47.0 mm, 75 parts (4 on the bottom side), 51 nets.

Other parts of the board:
LOGO1: SFE_LOGO_NAME_FLAME.1_INCH; SFE_LOGO_NAME_FLAME_.1
LOGO5: OSHW-LOGOS; OSHW-LOGO-S

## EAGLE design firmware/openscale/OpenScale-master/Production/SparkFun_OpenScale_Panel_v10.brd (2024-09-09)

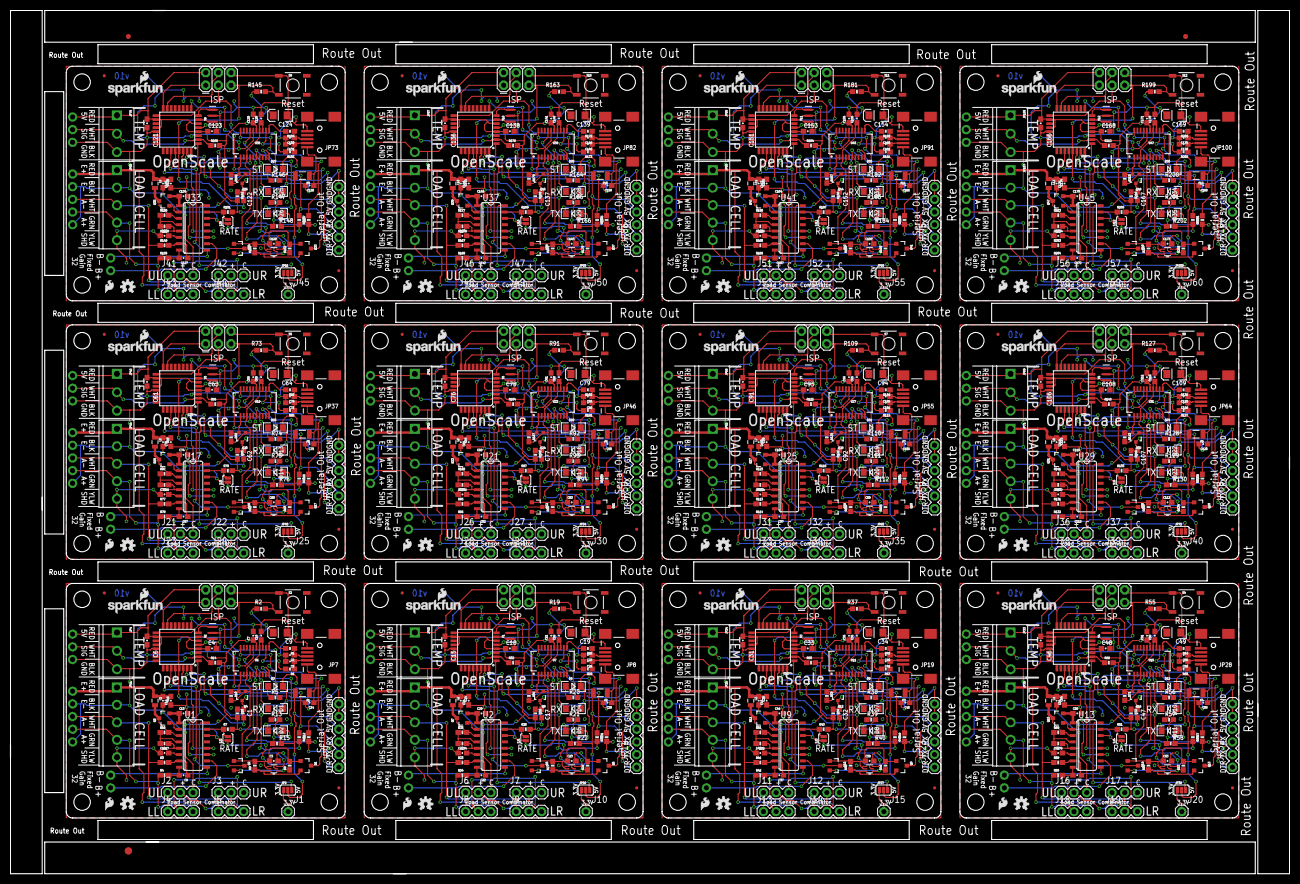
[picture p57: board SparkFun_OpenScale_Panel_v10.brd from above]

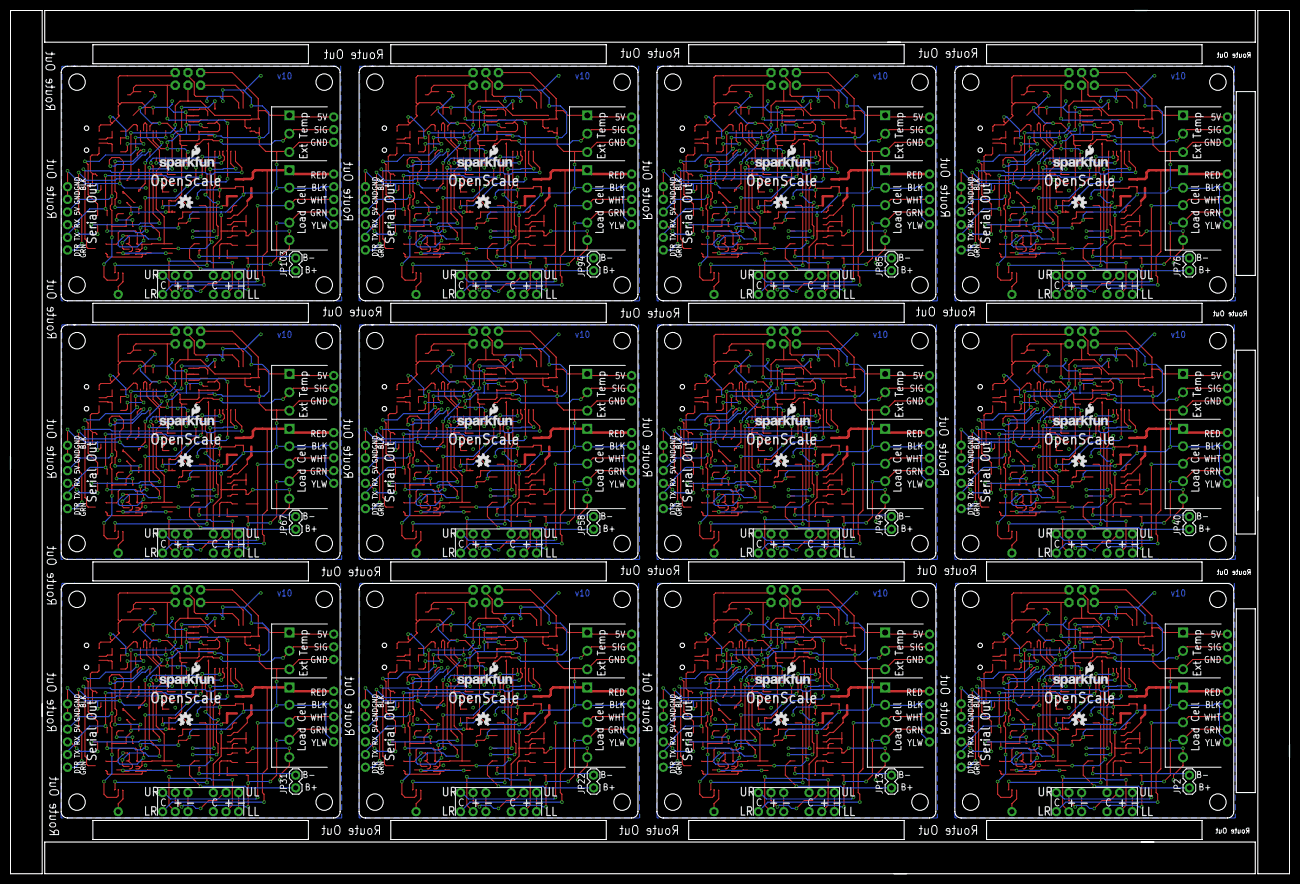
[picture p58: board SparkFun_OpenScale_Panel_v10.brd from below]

Board: 2 copper layers, 256.3 x 173.0 mm, 891 parts (48 on the bottom side), 612 nets.

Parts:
C1, C3, C6, C7, C8, C10, C11, C14, C15, C16, C17, C20, C21, C22, C23, C24, C27, C30, C31, C32, C35, C36, C37, C38, C39, C42, C45, C46, C47, C50, C51, C52, C53, C54, C57, C60, C61, C62, C65, C66, C67, C68, C69, C72, C75, C76, C77, C80, C81, C82, C83, C84, C87, C90, C91, C92, C95, C96, C97, C98, C99, C102, C105, C106, C107, C110, C111, C112, C113, C114, C117, C120, C121, C122, C125, C126, C127, C128, C129, C132, C135, C136, C137, C140, C141, C142, C143, C144, C147, C150, C151, C152, C155, C156, C157, C158, C159, C162, C165, C166, C167, C170, C171, C172, C173, C174, C177, C180: 0.1uF; 0603-CAP
C2, C5, C25, C26, C40, C41, C55, C56, C70, C71, C85, C86, C100, C101, C115, C116, C130, C131, C145, C146, C160, C161, C175, C176: 47pF; 0603-CAP
C4, C12, C13, C18, C28, C29, C33, C43, C44, C48, C58, C59, C63, C73, C74, C78, C88, C89, C93, C103, C104, C108, C118, C119, C123, C133, C134, C138, C148, C149, C153, C163, C164, C168, C178, C179: 1.0uF; 0603-CAP
C9, C19, C34, C49, C64, C79, C94, C109, C124, C139, C154, C169: 10uF; EIA3216
D1, D4, D7, D10, D13, D16, D19, D22, D25, D28, D31, D34: Yellow; LED-1206
D2, D5, D8, D11, D14, D17, D20, D23, D26, D29, D32, D35: GREEN; LED-1206
D3, D6, D9, D12, D15, D18, D21, D24, D27, D30, D33, D36: BLUE; LED-1206
E$1: FIDUCIAL-1.5X3
E$7, E$8: FIDUCIAL-1X2
F1, F2, F3, F4, F5, F6, F7, F8, F9, F10, F11, F12: PTCSMD; PTC-1206
FID1, FID2, FID3, FID4, FID5, FID6, FID7, FID8, FID9, FID10, FID11, FID12, FID13, FID14, FID15, FID16, FID17, FID18, FID19, FID20, FID21, FID22, FID23, FID24: FIDUCIALUFIDUCIAL; MICRO-FIDUCIAL
J1, J10, J15, J20, J25, J30, J35, J40, J45, J50, J55, J60: 3.3V; 1X01
J2, J6, J11, J16, J21, J26, J31, J36, J41, J46, J51, J56: UL; 1X03
J3, J7, J12, J17, J22, J27, J32, J37, J42, J47, J52, J57: UR; 1X03
J4, J8, J13, J18, J23, J28, J33, J38, J43, J48, J53, J58: LL; 1X03
J5, J9, J14, J19, J24, J29, J34, J39, J44, J49, J54, J59: LR; 1X03
JP1, JP12, JP21, JP30, JP39, JP48, JP57, JP66, JP75, JP84, JP93, JP102: Temp; 1X03_NO_SILK
JP2, JP13, JP22, JP31, JP40, JP49, JP58, JP67, JP76, JP85, JP94, JP103: Fixed Gain 32; 1X02
JP3, JP16, JP25, JP34, JP43, JP52, JP61, JP70, JP79, JP88, JP97, JP106: Load; 1X05_NO_SILK
JP4, JP15, JP24, JP33, JP42, JP51, JP60, JP69, JP78, JP87, JP96, JP105: Screw; SCREWTERMINAL-3.5MM-3_LOCK.007S
JP5, JP10, JP20, JP29, JP38, JP47, JP56, JP65, JP74, JP83, JP92, JP101: AVR_PRG; 2X3
JP6, JP18, JP27, JP36, JP45, JP54, JP63, JP72, JP81, JP90, JP99, JP108: JUMPER-PAD-3-2OF3_NC_BY_PASTE; PAD-JUMPER-3-2OF3_NC_BY_PASTE_YES_SILK_FULL_BOX
JP7, JP8, JP19, JP28, JP37, JP46, JP55, JP64, JP73, JP82, JP91, JP100: USBSMD; USB-MINIB
JP9, JP14, JP23, JP32, JP41, JP50, JP59, JP68, JP77, JP86, JP95, JP104: FTDI_BASIC
JP11, JP17, JP26, JP35, JP44, JP53, JP62, JP71, JP80, JP89, JP98, JP107: Screw Terminals; SCREWTERMINAL-3.5MM-5
L1, L2, L3, L4, L5, L6, L7, L8, L9, L10, L11, L12: 3.3uH; 0805
LOGO1, LOGO4, LOGO7, LOGO9, LOGO12, LOGO14, LOGO17, LOGO19, LOGO22, LOGO24, LOGO27, LOGO29, LOGO32, LOGO34, LOGO37, LOGO39, LOGO42, LOGO44, LOGO47, LOGO49, LOGO52, LOGO54, LOGO57, LOGO59: SFE_LOGO_NAME_FLAME.1_INCH; SFE_LOGO_NAME_FLAME_.1
LOGO2, LOGO5, LOGO6, LOGO10, LOGO11, LOGO15, LOGO16, LOGO20, LOGO21, LOGO25, LOGO26, LOGO30, LOGO31, LOGO35, LOGO36, LOGO40, LOGO41, LOGO45, LOGO46, LOGO50, LOGO51, LOGO55, LOGO56, LOGO60: OSHW-LOGOS; OSHW-LOGO-S
LOGO3, LOGO8, LOGO13, LOGO18, LOGO23, LOGO28, LOGO33, LOGO38, LOGO43, LOGO48, LOGO53, LOGO58: SFE_LOGO_FLAME.1_INCH; SFE_LOGO_FLAME_.1
Q1, Q2, Q5, Q6, Q9, Q10, Q13, Q14, Q17, Q18, Q21, Q22, Q25, Q26, Q29, Q30, Q33, Q34, Q37, Q38, Q41, Q42, Q45, Q46: 200mA/50V; SOT23-3
Q3, Q7, Q11, Q15, Q19, Q23, Q27, Q31, Q35, Q39, Q43, Q47: MMBT4403; SOT23-3
Q4, Q8, Q12, Q16, Q20, Q24, Q28, Q32, Q36, Q40, Q44, Q48: MOSFET-NCHANNEL2N7002PW; SOT323
R1, R6, R28, R29, R46, R47, R64, R65, R82, R83, R100, R101, R118, R119, R136, R137, R154, R155, R172, R173, R190, R191, R208, R209: 27; 0603
R2, R7, R10, R18, R19, R25, R35, R36, R37, R43, R53, R54, R55, R61, R71, R72, R73, R79, R89, R90, R91, R97, R107, R108, R109, R115, R125, R126, R127, R133, R143, R144, R145, R151, R161, R162, R163, R169, R179, R180, R181, R187, R197, R198, R199, R205, R215, R216: 10K; 0603-RES
R3, R4, R23, R24, R41, R42, R59, R60, R77, R78, R95, R96, R113, R114, R131, R132, R149, R150, R167, R168, R185, R186, R203, R204: 100; 0603-RES
R5, R11, R12, R13, R15, R20, R21, R22, R30, R31, R38, R39, R40, R48, R49, R56, R57, R58, R66, R67, R74, R75, R76, R84, R85, R92, R93, R94, R102, R103, R110, R111, R112, R120, R121, R128, R129, R130, R138, R139, R146, R147, R148, R156, R157, R164, R165, R166, R174, R175, R182, R183, R184, R192, R193, R200, R201, R202, R210, R211: 1K; 0603-RES
R8, R9, R14, R26, R27, R32, R44, R45, R50, R62, R63, R68, R80, R81, R86, R98, R99, R104, R116, R117, R122, R134, R135, R140, R152, R153, R158, R170, R171, R176, R188, R189, R194, R206, R207, R212: 4.7K; 0603-RES
R16, R33, R51, R69, R87, R105, R123, R141, R159, R177, R195, R213: 20k; 0603-RES
R17, R34, R52, R70, R88, R106, R124, R142, R160, R178, R196, R214: 8.2K; 0603-RES
S1, S2, S3, S4, S5, S6, S7, S8, S9, S10, S11, S12: Reset; TACTILE-SWITCH-SMD
SJ1, SJ2, SJ3, SJ4, SJ5, SJ6, SJ7, SJ8, SJ9, SJ10, SJ11, SJ12: JUMPER-PAD-2-NC_BY_PASTE; PAD-JUMPER-2-NC_BY_PASTE_YES_SILK
STANDOFF1, STANDOFF2, STANDOFF3, STANDOFF4, STANDOFF5, STANDOFF6, STANDOFF7, STANDOFF8, STANDOFF9, STANDOFF10, STANDOFF11, STANDOFF12, STANDOFF13, STANDOFF14, STANDOFF15, STANDOFF16, STANDOFF17, STANDOFF18, STANDOFF19, STANDOFF20, STANDOFF21, STANDOFF22, STANDOFF23, STANDOFF24, STANDOFF25, STANDOFF26, STANDOFF27, STANDOFF28, STANDOFF29, STANDOFF30, STANDOFF31, STANDOFF32, STANDOFF33, STANDOFF34, STANDOFF35, STANDOFF36, STANDOFF37, STANDOFF38, STANDOFF39, STANDOFF40, STANDOFF41, STANDOFF42, STANDOFF43, STANDOFF44, STANDOFF45, STANDOFF46, STANDOFF47, STANDOFF48: STAND-OFF
U1, U2, U9, U13, U17, U21, U25, U29, U33, U37, U41, U45: HX711; SO16
U3, U5, U10, U14, U18, U22, U26, U30, U34, U38, U42, U46: TMP102; SOT563
U4, U8, U12, U16, U20, U24, U28, U32, U36, U40, U44, U48: ATMEGA328P_TQFP; TQFP32-08
U6, U7, U11, U15, U19, U23, U27, U31, U35, U39, U43, U47: FT231XS; SSOP20_L
Y1, Y2, Y3, Y4, Y5, Y6, Y7, Y8, Y9, Y10, Y11, Y12: 16MHZ; RESONATOR-SMD

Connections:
1: J8.2, J9.2
2: J4.2, J5.2
3: J13.2, J14.2
3.3V: C3.1, C10.1, Q1.1, Q2.1, Q4.1, R8.2, R9.2, R10.2, U3.4, U3.5, U6.3, U6.13, U6.14
3.3V1: C20.1, C23.1, Q5.1, Q6.1, Q8.1, R26.2, R27.2, R35.2, U5.4, U5.5, U7.3, U7.13, U7.14
3.3V2: C35.1, C38.1, Q9.1, Q10.1, Q12.1, R44.2, R45.2, R53.2, U10.4, U10.5, U11.3, U11.13, U11.14
3.3V3: C50.1, C53.1, Q13.1, Q14.1, Q16.1, R62.2, R63.2, R71.2, U14.4, U14.5, U15.3, U15.13, U15.14
3.3V4: C65.1, C68.1, Q17.1, Q18.1, Q20.1, R80.2, R81.2, R89.2, U18.4, U18.5, U19.3, U19.13, U19.14
3.3V5: C80.1, C83.1, Q21.1, Q22.1, Q24.1, R98.2, R99.2, R107.2, U22.4, U22.5, U23.3, U23.13, U23.14
3.3V6: C95.1, C98.1, Q25.1, Q26.1, Q28.1, R116.2, R117.2, R125.2, U26.4, U26.5, U27.3, U27.13, U27.14
3.3V7: C110.1, C113.1, Q29.1, Q30.1, Q32.1, R134.2, R135.2, R143.2, U30.4, U30.5, U31.3, U31.13, U31.14
3.3V8: C125.1, C128.1, Q33.1, Q34.1, Q36.1, R152.2, R153.2, R161.2, U34.4, U34.5, U35.3, U35.13, U35.14
3.3V9: C140.1, C143.1, Q37.1, Q38.1, Q40.1, R170.2, R171.2, R179.2, U38.4, U38.5, U39.3, U39.13, U39.14
3.3V10: C155.1, C158.1, Q41.1, Q42.1, Q44.1, R188.2, R189.2, R197.2, U42.4, U42.5, U43.3, U43.13, U43.14
3.3V11: C170.1, C173.1, Q45.1, Q46.1, Q48.1, R206.2, R207.2, R215.2, U46.4, U46.5, U47.3, U47.13, U47.14
4: J18.2, J19.2
5: J23.2, J24.2
5V: C4.1, C6.1, C7.1, C9.A, C13.1, F1.2, JP1.1, JP4.1, JP5.2, JP6.2, JP9.VCC, Q3.2, R2.2, R7.2, R13.2, R14.2, R15.2, R18.2, U1.1, U4.4, U4.6, U4.18, U4.20, U6.15
5V1: C15.1, C18.1, C19.A, C21.1, C29.1, F2.2, JP10.2, JP12.1, JP14.VCC, JP15.1, JP18.2, Q7.2, R19.2, R21.2, R22.2, R25.2, R32.2, R36.2, U2.1, U7.15, U8.4, U8.6, U8.18, U8.20
5V2: C31.1, C33.1, C34.A, C36.1, C44.1, F3.2, JP20.2, JP21.1, JP23.VCC, JP24.1, JP27.2, Q11.2, R37.2, R39.2, R40.2, R43.2, R50.2, R54.2, U9.1, U11.15, U12.4, U12.6, U12.18, U12.20
5V3: C46.1, C48.1, C49.A, C51.1, C59.1, F4.2, JP29.2, JP30.1, JP32.VCC, JP33.1, JP36.2, Q15.2, R55.2, R57.2, R58.2, R61.2, R68.2, R72.2, U13.1, U15.15, U16.4, U16.6, U16.18, U16.20
5V4: C61.1, C63.1, C64.A, C66.1, C74.1, F5.2, JP38.2, JP39.1, JP41.VCC, JP42.1, JP45.2, Q19.2, R73.2, R75.2, R76.2, R79.2, R86.2, R90.2, U17.1, U19.15, U20.4, U20.6, U20.18, U20.20
5V5: C76.1, C78.1, C79.A, C81.1, C89.1, F6.2, JP47.2, JP48.1, JP50.VCC, JP51.1, JP54.2, Q23.2, R91.2, R93.2, R94.2, R97.2, R104.2, R108.2, U21.1, U23.15, U24.4, U24.6, U24.18, U24.20
5V6: C91.1, C93.1, C94.A, C96.1, C104.1, F7.2, JP56.2, JP57.1, JP59.VCC, JP60.1, JP63.2, Q27.2, R109.2, R111.2, R112.2, R115.2, R122.2, R126.2, U25.1, U27.15, U28.4, U28.6, U28.18, U28.20
5V7: C106.1, C108.1, C109.A, C111.1, C119.1, F8.2, JP65.2, JP66.1, JP68.VCC, JP69.1, JP72.2, Q31.2, R127.2, R129.2, R130.2, R133.2, R140.2, R144.2, U29.1, U31.15, U32.4, U32.6, U32.18, U32.20
5V8: C121.1, C123.1, C124.A, C126.1, C134.1, F9.2, JP74.2, JP75.1, JP77.VCC, JP78.1, JP81.2, Q35.2, R145.2, R147.2, R148.2, R151.2, R158.2, R162.2, U33.1, U35.15, U36.4, U36.6, U36.18, U36.20
5V9: C136.1, C138.1, C139.A, C141.1, C149.1, F10.2, JP83.2, JP84.1, JP86.VCC, JP87.1, JP90.2, Q39.2, R163.2, R165.2, R166.2, R169.2, R176.2, R180.2, U37.1, U39.15, U40.4, U40.6, U40.18, U40.20
5V10: C151.1, C153.1, C154.A, C156.1, C164.1, F11.2, JP92.2, JP93.1, JP95.VCC, JP96.1, JP99.2, Q43.2, R181.2, R183.2, R184.2, R187.2, R194.2, R198.2, U41.1, U43.15, U44.4, U44.6, U44.18, U44.20
5V11: C166.1, C168.1, C169.A, C171.1, C179.1, F12.2, JP101.2, JP102.1, JP104.VCC, JP105.1, JP108.2, Q47.2, R199.2, R201.2, R202.2, R205.2, R212.2, R216.2, U45.1, U47.15, U48.4, U48.6, U48.18, U48.20
6: J28.2, J29.2
7: J33.2, J34.2
8: J38.2, J39.2
9: J43.2, J44.2
10: J48.2, J49.2
11: J53.2, J54.2
12: J58.2, J59.2
A+: J4.3, JP3.2, JP11.4, R4.1
A+1: J8.3, JP16.2, JP17.4, R24.1
A+2: J13.3, JP25.2, JP26.4, R42.1
A+3: J18.3, JP34.2, JP35.4, R60.1
A+4: J23.3, JP43.2, JP44.4, R78.1
A+5: J28.3, JP52.2, JP53.4, R96.1
A+6: J33.3, JP61.2, JP62.4, R114.1
A+7: J38.3, JP70.2, JP71.4, R132.1
A+8: J43.3, JP79.2, JP80.4, R150.1
A+9: J48.3, JP88.2, JP89.4, R168.1
A+10: J53.3, JP97.2, JP98.4, R186.1
A+11: J58.3, JP106.2, JP107.4, R204.1
A-: J3.3, JP3.3, JP11.3, R3.1
A-1: J7.3, JP16.3, JP17.3, R23.1
A-2: J12.3, JP25.3, JP26.3, R41.1
A-3: J17.3, JP34.3, JP35.3, R59.1
A-4: J22.3, JP43.3, JP44.3, R77.1
A-5: J27.3, JP52.3, JP53.3, R95.1
A-6: J32.3, JP61.3, JP62.3, R113.1
A-7: J37.3, JP70.3, JP71.3, R131.1
A-8: J42.3, JP79.3, JP80.3, R149.1
A-9: J47.3, JP88.3, JP89.3, R167.1
A-10: J52.3, JP97.3, JP98.3, R185.1
A-11: J57.3, JP106.3, JP107.3, R203.1
ALERT: U3.3, U4.9
ALERT1: U5.3, U8.9
ALERT2: U10.3, U12.9
ALERT3: U14.3, U16.9
ALERT4: U18.3, U20.9
ALERT5: U22.3, U24.9
ALERT6: U26.3, U28.9
ALERT7: U30.3, U32.9
ALERT8: U34.3, U36.9
ALERT9: U38.3, U40.9
ALERT10: U42.3, U44.9
ALERT11: U46.3, U48.9
AVDD: C12.2, C16.1, J5.3, JP3.5, JP11.1, L1.1
AVDD1: C24.1, C28.2, J9.3, JP16.5, JP17.1, L2.1
AVDD2: C39.1, C43.2, J14.3, JP25.5, JP26.1, L3.1
AVDD3: C54.1, C58.2, J19.3, JP34.5, JP35.1, L4.1
AVDD4: C69.1, C73.2, J24.3, JP43.5, JP44.1, L5.1
AVDD5: C84.1, C88.2, J29.3, JP52.5, JP53.1, L6.1
AVDD6: C99.1, C103.2, J34.3, JP61.5, JP62.1, L7.1
AVDD7: C114.1, C118.2, J39.3, JP70.5, JP71.1, L8.1
AVDD8: C129.1, C133.2, J44.3, JP79.5, JP80.1, L9.1
AVDD9: C144.1, C148.2, J49.3, JP88.5, JP89.1, L10.1
AVDD10: C159.1, C163.2, J54.3, JP97.5, JP98.1, L11.1
AVDD11: C174.1, C178.2, J59.3, JP106.5, JP107.1, L12.1
B+: JP2.1, U1.10
B+1: JP13.1, U2.10
B+2: JP22.1, U9.10
B+3: JP31.1, U13.10
B+4: JP40.1, U17.10
B+5: JP49.1, U21.10
B+6: JP58.1, U25.10
B+7: JP67.1, U29.10
B+8: JP76.1, U33.10
B+9: JP85.1, U37.10
B+10: JP94.1, U41.10
B+11: JP103.1, U45.10
B-: JP2.2, U1.9
B-1: JP13.2, U2.9
B-2: JP22.2, U9.9
B-3: JP31.2, U13.9
B-4: JP40.2, U17.9
B-5: JP49.2, U21.9
B-6: JP58.2, U25.9
B-7: JP67.2, U29.9
B-8: JP76.2, U33.9
B-9: JP85.2, U37.9
B-10: JP94.2, U41.9
B-11: JP103.2, U45.9
D1: JP10.4, U8.15
D2: JP10.1, U8.16
D3: JP10.3, R20.2, U8.17
D4: JP20.4, U12.15
D5: JP20.1, U12.16
D6: JP20.3, R38.2, U12.17
D7: JP29.4, U16.15
D8: JP29.1, U16.16
D9: JP29.3, R56.2, U16.17
D10: JP38.4, U20.15
D11: JP5.4, U4.15
D12: JP5.1, U4.16
D13: JP5.3, R5.2, U4.17
D14: JP38.1, U20.16
D15: JP38.3, R74.2, U20.17
D16: JP47.4, U24.15
D17: JP47.1, U24.16
D18: JP47.3, R92.2, U24.17
D19: JP56.4, U28.15
D20: JP56.1, U28.16
D21: JP56.3, R110.2, U28.17
D22: JP65.4, U32.15
D23: JP65.1, U32.16
D24: JP65.3, R128.2, U32.17
D25: JP74.4, U36.15
D26: JP74.1, U36.16
D27: JP74.3, R146.2, U36.17
D28: JP83.4, U40.15
D29: JP83.1, U40.16
D30: JP83.3, R164.2, U40.17
D31: JP92.4, U44.15
D32: JP92.1, U44.16
D33: JP92.3, R182.2, U44.17
D34: JP101.4, U48.15
D35: JP101.1, U48.16
D36: JP101.3, R200.2, U48.17
DTR: C1.1, JP9.DTR, Q4.3, R18.1
DTR1: C17.1, JP14.DTR, Q8.3, R36.1
DTR2: C32.1, JP23.DTR, Q12.3, R54.1
DTR3: C47.1, JP32.DTR, Q16.3, R72.1
DTR4: C62.1, JP41.DTR, Q20.3, R90.1
DTR5: C77.1, JP50.DTR, Q24.3, R108.1
DTR6: C92.1, JP59.DTR, Q28.3, R126.1
DTR7: C107.1, JP68.DTR, Q32.3, R144.1
DTR8: C122.1, JP77.DTR, Q36.3, R162.1
DTR9: C137.1, JP86.DTR, Q40.3, R180.1
DTR10: C152.1, JP95.DTR, Q44.3, R198.1
DTR11: C167.1, JP104.DTR, Q48.3, R216.1
GND: C2.2, C3.2, C4.2, C5.2, C6.2, C7.2, C9.C, C10.2, C11.1, C12.1, C13.2, C14.2, C16.2, D3.C, J2.3, JP1.3, JP3.1, JP3.4, JP4.3, JP5.6, JP7.GND, JP9.CTS, JP9.GND, JP11.2, JP11.5, R17.1, S2.1, SJ2.1, U1.5, U1.14, U3.2, U4.3, U4.5, U4.21, U6.6, U6.16, Y2.2
GND1: C15.2, C18.2, C19.C, C20.2, C21.2, C23.2, C24.2, C25.2, C26.2, C27.1, C28.1, C29.2, C30.2, D6.C, J6.3, JP8.GND, JP10.6, JP12.3, JP14.CTS, JP14.GND, JP15.3, JP16.1, JP16.4, JP17.2, JP17.5, R34.1, S1.1, SJ1.1, U2.5, U2.14, U5.2, U7.6, U7.16, U8.3, U8.5, U8.21, Y1.2
GND2: C31.2, C33.2, C34.C, C35.2, C36.2, C38.2, C39.2, C40.2, C41.2, C42.1, C43.1, C44.2, C45.2, D9.C, J11.3, JP19.GND, JP20.6, JP21.3, JP23.CTS, JP23.GND, JP24.3, JP25.1, JP25.4, JP26.2, JP26.5, R52.1, S3.1, SJ3.1, U9.5, U9.14, U10.2, U11.6, U11.16, U12.3, U12.5, U12.21, Y3.2
GND3: C46.2, C48.2, C49.C, C50.2, C51.2, C53.2, C54.2, C55.2, C56.2, C57.1, C58.1, C59.2, C60.2, D12.C, J16.3, JP28.GND, JP29.6, JP30.3, JP32.CTS, JP32.GND, JP33.3, JP34.1, JP34.4, JP35.2, JP35.5, R70.1, S4.1, SJ4.1, U13.5, U13.14, U14.2, U15.6, U15.16, U16.3, U16.5, U16.21, Y4.2
GND4: C61.2, C63.2, C64.C, C65.2, C66.2, C68.2, C69.2, C70.2, C71.2, C72.1, C73.1, C74.2, C75.2, D15.C, J21.3, JP37.GND, JP38.6, JP39.3, JP41.CTS, JP41.GND, JP42.3, JP43.1, JP43.4, JP44.2, JP44.5, R88.1, S5.1, SJ5.1, U17.5, U17.14, U18.2, U19.6, U19.16, U20.3, U20.5, U20.21, Y5.2
GND5: C76.2, C78.2, C79.C, C80.2, C81.2, C83.2, C84.2, C85.2, C86.2, C87.1, C88.1, C89.2, C90.2, D18.C, J26.3, JP46.GND, JP47.6, JP48.3, JP50.CTS, JP50.GND, JP51.3, JP52.1, JP52.4, JP53.2, JP53.5, R106.1, S6.1, SJ6.1, U21.5, U21.14, U22.2, U23.6, U23.16, U24.3, U24.5, U24.21, Y6.2
GND6: C91.2, C93.2, C94.C, C95.2, C96.2, C98.2, C99.2, C100.2, C101.2, C102.1, C103.1, C104.2, C105.2, D21.C, J31.3, JP55.GND, JP56.6, JP57.3, JP59.CTS, JP59.GND, JP60.3, JP61.1, JP61.4, JP62.2, JP62.5, R124.1, S7.1, SJ7.1, U25.5, U25.14, U26.2, U27.6, U27.16, U28.3, U28.5, U28.21, Y7.2
GND7: C106.2, C108.2, C109.C, C110.2, C111.2, C113.2, C114.2, C115.2, C116.2, C117.1, C118.1, C119.2, C120.2, D24.C, J36.3, JP64.GND, JP65.6, JP66.3, JP68.CTS, JP68.GND, JP69.3, JP70.1, JP70.4, JP71.2, JP71.5, R142.1, S8.1, SJ8.1, U29.5, U29.14, U30.2, U31.6, U31.16, U32.3, U32.5, U32.21, Y8.2
GND8: C121.2, C123.2, C124.C, C125.2, C126.2, C128.2, C129.2, C130.2, C131.2, C132.1, C133.1, C134.2, C135.2, D27.C, J41.3, JP73.GND, JP74.6, JP75.3, JP77.CTS, JP77.GND, JP78.3, JP79.1, JP79.4, JP80.2, JP80.5, R160.1, S9.1, SJ9.1, U33.5, U33.14, U34.2, U35.6, U35.16, U36.3, U36.5, U36.21, Y9.2
GND9: C136.2, C138.2, C139.C, C140.2, C141.2, C143.2, C144.2, C145.2, C146.2, C147.1, C148.1, C149.2, C150.2, D30.C, J46.3, JP82.GND, JP83.6, JP84.3, JP86.CTS, JP86.GND, JP87.3, JP88.1, JP88.4, JP89.2, JP89.5, R178.1, S10.1, SJ10.1, U37.5, U37.14, U38.2, U39.6, U39.16, U40.3, U40.5, U40.21, Y10.2
GND10: C151.2, C153.2, C154.C, C155.2, C156.2, C158.2, C159.2, C160.2, C161.2, C162.1, C163.1, C164.2, C165.2, D33.C, J51.3, JP91.GND, JP92.6, JP93.3, JP95.CTS, JP95.GND, JP96.3, JP97.1, JP97.4, JP98.2, JP98.5, R196.1, S11.1, SJ11.1, U41.5, U41.14, U42.2, U43.6, U43.16, U44.3, U44.5, U44.21, Y11.2
GND11: C166.2, C168.2, C169.C, C170.2, C171.2, C173.2, C174.2, C175.2, C176.2, C177.1, C178.1, C179.2, C180.2, D36.C, J56.3, JP100.GND, JP101.6, JP102.3, JP104.CTS, JP104.GND, JP105.3, JP106.1, JP106.4, JP107.2, JP107.5, R214.1, S12.1, SJ12.1, U45.5, U45.14, U46.2, U47.6, U47.16, U48.3, U48.5, U48.21, Y12.2
LC_DOUT: U1.12, U4.32
LC_DOUT1: U2.12, U8.32
LC_DOUT2: U9.12, U12.32
LC_DOUT3: U13.12, U16.32
LC_DOUT4: U17.12, U20.32
LC_DOUT5: U21.12, U24.32
LC_DOUT6: U25.12, U28.32
LC_DOUT7: U29.12, U32.32
LC_DOUT8: U33.12, U36.32
LC_DOUT9: U37.12, U40.32
LC_DOUT10: U41.12, U44.32
LC_DOUT11: U45.12, U48.32
LC_SCK: U1.11, U4.1
LC_SCK1: U2.11, U8.1
LC_SCK2: U9.11, U12.1
LC_SCK3: U13.11, U16.1
LC_SCK4: U17.11, U20.1
LC_SCK5: U21.11, U24.1
LC_SCK6: U25.11, U28.1
LC_SCK7: U29.11, U32.1
LC_SCK8: U33.11, U36.1
LC_SCK9: U37.11, U40.1
LC_SCK10: U41.11, U44.1
LC_SCK11: U45.11, U48.1
LV_SCL: Q2.2, R8.1, U3.1
LV_SCL1: Q6.2, R26.1, U5.1
LV_SCL2: Q10.2, R44.1, U10.1
LV_SCL3: Q14.2, R62.1, U14.1
LV_SCL4: Q18.2, R80.1, U18.1
LV_SCL5: Q22.2, R98.1, U22.1
LV_SCL6: Q26.2, R116.1, U26.1
LV_SCL7: Q30.2, R134.1, U30.1
LV_SCL8: Q34.2, R152.1, U34.1
LV_SCL9: Q38.2, R170.1, U38.1
LV_SCL10: Q42.2, R188.1, U42.1
LV_SCL11: Q46.2, R206.1, U46.1
LV_SDA: Q1.2, R9.1, U3.6
LV_SDA1: Q5.2, R27.1, U5.6
LV_SDA2: Q9.2, R45.1, U10.6
LV_SDA3: Q13.2, R63.1, U14.6
LV_SDA4: Q17.2, R81.1, U18.6
LV_SDA5: Q21.2, R99.1, U22.6
LV_SDA6: Q25.2, R117.1, U26.6
LV_SDA7: Q29.2, R135.1, U30.6
LV_SDA8: Q33.2, R153.1, U34.6
LV_SDA9: Q37.2, R171.1, U38.6
LV_SDA10: Q41.2, R189.1, U42.6
LV_SDA11: Q45.2, R207.1, U46.6
unnamed: U4.7, Y2.1
unnamed: D3.A, R5.1
unnamed: U4.8, Y2.3
unnamed: C5.1, JP7.D-, R6.1
unnamed: D1.A, R13.1
unnamed: D2.A, R15.1
unnamed: C2.1, JP7.D+, R1.1
unnamed: R6.2, U6.12
unnamed: R7.1, SJ2.2, U1.15
unnamed: C8.1, R3.2, U1.7
unnamed: C8.2, R4.2, U1.8
unnamed: C14.1, F1.1, JP7.VBUS
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

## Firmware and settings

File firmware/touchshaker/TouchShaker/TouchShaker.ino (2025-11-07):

#include "Arduino.h"
#include "ArCOM.h"

#define HANDLE_MOTOR_BOTTOM 1
#ifdef HANDLES_MOTOR_BOTTOM
#define LOW_DIR_H HIGH
#define HIGH_DIR_H LOW
#else
#define LOW_DIR_H LOW
#define HIGH_DIR_H HIGH
#endif

#define SPOUT_MOTOR_BOTTOM 1
#ifdef SPOUT_MOTOR_BOTTOM
#define LOW_DIR_S HIGH
#define HIGH_DIR_S LOW
#else
#define LOW_DIR_S LOW
#define HIGH_DIR_S HIGH
#endif

// –--–--–--–--–--–--–--–--–--–--–--–--–--–--–--–--–--–--–--–--–--–--–--–--–--–--–--–--–--–--–--–--–--–--–--–-- 
// This version includes:
// control two stepper motors to move the sputes
// control two stepper motors to move levers
// reads water spout and lever touches using capacitive sensing.
// serial communication with bpod v2 state machine
// –--–--–--–--–--–--–--–--–--–--–--–--–--–--–--–--–--–--–--–--–--–--–--–--–--–--–--–--–--–--–--–--–--–--–--–-- 

// Serial-write variables
unsigned long FirmwareVersion = 2;
char moduleName[] = "TouchShaker"; // Name of module for manual override UI and state machine

ArCOM Serial1COM(Serial1); // UART serial port

unsigned long clocker = millis();
unsigned long stimClocker = millis();
unsigned long trialClocker = millis();
int FSMheader = 0;
const int sRateLicks = 5; // This is the minimum duration of lick events that are send to bpod.
const int sRateLever = 10; // This is the number of ms for outputs to be during levertouch. Signal remains live until 'sRateLever' ms after the last contact.

/* ################################################# ############## PIN CONFIGURATION ################### #################################################### */
// TTL Outputs
#define PIN_STIMTRIG 21 // stimulus trigger that can be switched by serial command 'MAKE_STIMTRIGGER'
#define PIN_TRIALTRIG 4 // trial-start trigger that can be switched by serial command 'MAKE_TRIALTRIGGER'
#define PIN_CAMTIMER 3 // Trigger to synchronize camera acquisition. Sends TTL for 'camTrigDur' with an inter-pulse of 'camTrigRate'.

// Inputs for lick sensors
#define LEVERSENSOR_L 19 // touch line for lever touch
#define LEVERSENSOR_R 20 // touch line for lever touch
#define SPOUTSENSOR_L 15 // touch line for left spout
#define SPOUTSENSOR_R 16 // touch line for right spout

// Pins for stepper - spouts
#define PIN_SPOUTOUT_L 5
#define PIN_SPOUTOUT_R 6
#define PIN_SPOUTSTEP_L 13
#define PIN_SPOUTDIR_L 14
#define PIN_SPOUTSTEP_R 17
#define PIN_SPOUTDIR_R 18

// Pins for stepper - handles
#define PIN_LEVEROUT_L 7
#define PIN_LEVEROUT_R 8
#define PIN_LEVERSTEP_L 9
#define PIN_LEVERDIR_L 10
#define PIN_LEVERSTEP_R 11
#define PIN_LEVERDIR_R 12

/* ################################################# ########### UART/BPOD COMMUNICATION ################ #################################################### */
// Byte codes for serial communication
// inputs
#define MODULE_INFO 255
#define HWRESET 128
#define START_TRIAL 70
#define ADJUST_SPOUTES 71
#define ADJUST_LEVER 72
#define ADJUST_SPOUTSPEED 73
#define ADJUST_LEVERSPEED 74
#define ADJUST_TOUCHLEVEL 75
#define CHECK_LEVERS 76
#define MAKE_STIMTRIGGER 77
#define MAKE_TRIALTRIGGER 78
#define INCREASE_SPOUTTHRESH_L 80
#define DECREASE_SPOUTTHRESH_L 81
#define INCREASE_SPOUTTHRESH_R 82
#define DECREASE_SPOUTTHRESH_R 83
#define INCREASE_LEVERTHRESH_L 84
#define DECREASE_LEVERTHRESH_L 85
#define INCREASE_LEVERTHRESH_R 86
#define DECREASE_LEVERTHRESH_R 87
#define SET_TOUCHLEVELS 89
#define GET_TOUCHLEVELS 95
#define IS_MOVING 88

// outputs
#define LEFT_SPOUT_TOUCH 1
#define RIGHT_SPOUT_TOUCH 2
#define LEFT_SPOUT_RELEASE 3
#define RIGHT_SPOUT_RELEASE 4
#define LEFT_HANDLE_TOUCH 5
#define RIGHT_HANDLE_TOUCH 6
#define BOTH_HANDLES_TOUCH 7
#define LEFT_HANDLE_RELEASE 8
#define RIGHT_HANDLE_RELEASE 9
#define OK 14
#define FAIL 15

// other serial commands during the trial
#define SPOUTS_IN 101
#define SPOUTS_OUT 106
#define LEFT_SPOUT_OUT 102
#define RIGHT_SPOUT_OUT 103
#define LEVER_IN 104
#define LEVER_OUT 105

/* ################################################# ##################### VARIABLES #################### #################################################### */
// Servo vars
float lServoIn = 10;
float lServoOut = 0;
float lServoAdjust = 0;
float lServoCurrent = 0;
float rServoIn = 10;
float rServoOut = 0;
float rServoAdjust = 0;
float rServoCurrent = 0;
float leverIn = 10;
float leverOut = 0;
float leverAdjust = 0;
float leverCurrent = 0;
float spoutSpeed = 50000;
float leverSpeed = 50000;

unsigned long lSpoutClocker = micros();
unsigned long rSpoutClocker = micros();
unsigned long lClocker = micros();
unsigned long touchClocker_L = millis();
unsigned long touchClocker_R = millis();

int lSpoutInc = 1000;
int rSpoutInc = 1000;
int leverInc = 1000;
int touchChangeInc = 2;

// flags for current servo states. Required to control servo speed
bool stimTrigger = false;
bool trialTrigger = false;
bool spoutMoves = false;
bool lSpoutMovesIn = false;
bool lSpoutMovesOut = true;
bool lSpoutMovesAdjust = false;
bool rSpoutMovesIn = false;
bool rSpoutMovesOut = true;
bool rSpoutMovesAdjust = false;
bool leverMoves = false;
bool lMovesIn = false;
bool lMovesOut = true;
bool lMovesAdjust = false;

unsigned long spoutClocker_L = millis();
unsigned long spoutClocker_R = millis();

// Touch variables
int touchAdjustDur = 2000;
int touchThresh = 3;
int touchThreshOffset = 50;
bool touchAdjust = false;
int touchData[4];
float meanTouchVals[4];
float stdTouchVals[4];
float touchVal = 0;
long int sampleCnt[] = {0, 0};
unsigned long adjustClocker = millis();
int runningAvg[2] = {0, 0};
float avgWeight = 5000;

// Other variables
bool midRead = false;
bool spoutTouch_L = false;
bool spoutTouch_R = false;
bool leverTouch_L = false;
bool leverTouch_R = false;
bool leverTouch_BOTH = false;
bool findSpoutOut[2] = {true, true};
bool findLeverOut[2] = {true, true};
int stepPulse = 10;
int stimDur = 100;
int trialDur = 50;
float temp[10];
int camTrigRate = 90;
unsigned long usbClocker = millis();
int usbRate = 30;

// volatile long cameraFramesCounter = 0;

void setup() {
  Serial1.begin(1312500);
  Serial.begin(9600);

  // Servo pins
  pinMode(PIN_SPOUTSTEP_L, OUTPUT);
  pinMode(PIN_SPOUTSTEP_R, OUTPUT);
  pinMode(PIN_SPOUTDIR_L, OUTPUT);
  pinMode(PIN_SPOUTDIR_R, OUTPUT);
  pinMode(PIN_LEVERSTEP_L, OUTPUT);
  pinMode(PIN_LEVERSTEP_R, OUTPUT);
  pinMode(PIN_LEVERDIR_L, OUTPUT);
  pinMode(PIN_LEVERDIR_R, OUTPUT);

  // Digital outputs
  pinMode(PIN_STIMTRIG, OUTPUT);
  pinMode(PIN_TRIALTRIG, OUTPUT);

  // Stepper range inputs
  pinMode(PIN_SPOUTOUT_L, INPUT_PULLUP);
  pinMode(PIN_SPOUTOUT_R, INPUT_PULLUP);
  pinMode(PIN_LEVEROUT_L, INPUT_PULLUP);
  pinMode(PIN_LEVEROUT_R, INPUT_PULLUP);

  // Touch sensors
  pinMode(SPOUTSENSOR_L, INPUT);
  pinMode(SPOUTSENSOR_R, INPUT);
}
void loop() {
  // Handle serial commands from Bpod
  if (Serial1.available()) {
    handleSerialInput();
  }

  // Touch sensors update
  updateTouchSensors();

  // Move spouts if commanded
  updateSpouts();

  // Move levers if commanded
  updateLevers();

  // Handle trial and stim triggers
  if (stimTrigger) {
    digitalWrite(PIN_STIMTRIG, HIGH);
    delay(stimDur);
    digitalWrite(PIN_STIMTRIG, LOW);
    stimTrigger = false;
  }

  if (trialTrigger) {
    digitalWrite(PIN_TRIALTRIG, HIGH);
    delay(trialDur);
    digitalWrite(PIN_TRIALTRIG, LOW);
    trialTrigger = false;
  }

  // Camera trigger
  static unsigned long lastCamTrigger = 0;
  if (millis() - lastCamTrigger > camTrigRate) {
    digitalWrite(PIN_CAMTIMER, HIGH);
    delay(2); // pulse duration in ms
    digitalWrite(PIN_CAMTIMER, LOW);
    lastCamTrigger = millis();
  }
}

// ======================== SERIAL COMMAND HANDLER ========================
void handleSerialInput() {
  byte cmd = Serial1.read();

  switch (cmd) {
    case MODULE_INFO:
      Serial1.write(FirmwareVersion);
      Serial1.write(moduleName);
      break;
    case HWRESET:
      //NVIC_SystemReset();
      Serial1.write(OK);
      SCB_AIRCR = 0x05FA0004;  // works on Teensy 4.x
      break;
    case START_TRIAL:
      trialTrigger = true;
      break;
    case MAKE_STIMTRIGGER:
      stimTrigger = true;
      break;
    case SPOUTS_IN:
      lSpoutMovesIn = true;
      rSpoutMovesIn = true;
      break;
    case SPOUTS_OUT:
      lSpoutMovesOut = true;
      rSpoutMovesOut = true;
      break;
    case LEFT_SPOUT_OUT:
      lSpoutMovesOut = true;
      break;
    case RIGHT_SPOUT_OUT:
      rSpoutMovesOut = true;
      break;
    case LEVER_IN:
      lMovesIn = true;
      lMovesOut = false;
      break;
    case LEVER_OUT:
      lMovesOut = true;
      lMovesIn = false;
      break;
    default:
      Serial1.write(FAIL);
      break;
  }
}

// ======================== TOUCH SENSOR UPDATE ===========================
void updateTouchSensors() {
  int lTouch = analogRead(SPOUTSENSOR_L);
  int rTouch = analogRead(SPOUTSENSOR_R);
  int lLever = analogRead(LEVERSENSOR_L);
  int rLever = analogRead(LEVERSENSOR_R);

  // Simple thresholding
  spoutTouch_L = lTouch > touchThresh;
  spoutTouch_R = rTouch > touchThresh;
  leverTouch_L = lLever > touchThresh;
  leverTouch_R = rLever > touchThresh;
  leverTouch_BOTH = leverTouch_L && leverTouch_R;

  // Send events to Bpod if needed
  if (spoutTouch_L) Serial1.write(LEFT_SPOUT_TOUCH);
  if (spoutTouch_R) Serial1.write(RIGHT_SPOUT_TOUCH);
  if (leverTouch_L) Serial1.write(LEFT_HANDLE_TOUCH);
  if (leverTouch_R) Serial1.write(RIGHT_HANDLE_TOUCH);
  if (leverTouch_BOTH) Serial1.write(BOTH_HANDLES_TOUCH);
}

// ======================== SPOUT CONTROL ================================
void updateSpouts() {
  if (lSpoutMovesIn) moveSpout(PIN_SPOUTSTEP_L, PIN_SPOUTDIR_L, LOW_DIR_H, lSpoutInc);
  if (lSpoutMovesOut) moveSpout(PIN_SPOUTSTEP_L, PIN_SPOUTDIR_L, HIGH_DIR_H, lSpoutInc);
  if (rSpoutMovesIn) moveSpout(PIN_SPOUTSTEP_R, PIN_SPOUTDIR_R, LOW_DIR_H, rSpoutInc);
  if (rSpoutMovesOut) moveSpout(PIN_SPOUTSTEP_R, PIN_SPOUTDIR_R, HIGH_DIR_H, rSpoutInc);
}

void moveSpout(int stepPin, int dirPin, int direction, int steps) {
  digitalWrite(dirPin, direction);
  for (int i = 0; i < steps; i++) {
    digitalWrite(stepPin, HIGH);
    delayMicroseconds(spoutSpeed);
    digitalWrite(stepPin, LOW);
    delayMicroseconds(spoutSpeed);
  }
}

// ======================== LEVER CONTROL ================================
void updateLevers() {
  if (lMovesIn) moveLever(PIN_LEVERSTEP_L, PIN_LEVERDIR_L, LOW_DIR_H, leverInc);
  if (lMovesOut) moveLever(PIN_LEVERSTEP_L, PIN_LEVERDIR_L, HIGH_DIR_H, leverInc);
  if (lMovesAdjust) moveLever(PIN_LEVERSTEP_L, PIN_LEVERDIR_L, LOW_DIR_H, leverInc);
}

void moveLever(int stepPin, int dirPin, int direction, int steps) {
  digitalWrite(dirPin, direction);
  for (int i = 0; i < steps; i++) {
    digitalWrite(stepPin, HIGH);
    delayMicroseconds(leverSpeed);
    digitalWrite(stepPin, LOW);
    delayMicroseconds(leverSpeed);
  }
}

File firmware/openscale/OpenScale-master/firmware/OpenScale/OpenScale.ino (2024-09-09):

/*
  OpenScale: A serial interface for reading and configuring load cells.
  By: Nathan Seidle
  SparkFun Electronics
  Date: November 24th, 2014
  License: This code is public domain but you buy me a beer if you use this and we meet someday (Beerware license).

  This example code uses bogde's excellent library: https://github.com/bogde/HX711
  SparkFun spends a lot of time and energy building open source hardware and writing public domain code.
  Please consider supporting SparkFun by buying a product or kit.

  OpenScale is a simple board that allows a user to read and configure all types of load cells.
  It relies on the HX711 load cell amplifier.

  How to use:
  1) Wire your load cell to the board using the 4-pin connection (E+/-, A+/-) or the RJ45 connection.
  2) Attach board to USB and open terminal at 9600bps
  3) Press x to bring up settings menu
  4) Select units LBS/KG
  5) Tare the scale with no weight on the scale
  6) Calibrate the scale: Remove any weight, start calibration routine, place weight on scale, type
  in the weight placed on the scale.
  7) Press x and test your scale

  OpenScale ships with an Arduino/Optiboot 115200bps serial bootloader running at 16MHz so you can load new firmware
  with a simple serial connection. Select 'Arduino Uno' under the boards menu to reprogram the board.

  OpenScale runs at 9600bps by default. This is configurable to 1200, 2400, 4800, 9600, 19200, 38400, 57600, and 115200bps.

  After power up OpenScale will try reading the load cell and output a weight value.

  If you get OpenScale stuck into an unknown baudrate, there is a safety mechanism built-in. Tie the RX pin
  to ground and power up OpenScale. You should see the status LED blink at 1Hz for 2 seconds.
  Now power down OpenScale and remove the RX/GND jumper. OpenScale is now reset to 9600bps.

  To change the baud rate type 'x' to bring up configuration menu. Select the baud rate sub menu and enter
  the baud rate of your choice. You will then see a message for example 'Going to 9600bps...'.
  You will need to power down OpenScale, change your system UART settings to match the new OpenScale
  baud rate and then power OpenScale back up.

  STAT LED / D13 - toggles after each report

  If you're using this firmware with the HX711 breakout and an Uno here are the pins to hook up:
  Arduino pin 2 -> HX711 CLK
  3 -> DAT
  5V -> VCC
  GND -> GND

  Firmware versions:
  v1.0 - Original release
  v1.1 - Added trigger character
  v1.2 - 
  * Cleaned up white space and split to tabs for easier function finding
  * Changed the input method of many menu settings from the tedious +/- method
  to text enter. Now you can calibrate your system by typing in '0.5762' and OpenScale
  will figure out all the calibration factors.
  * Fixed a bug with the EEPROM defaulting to the wrong values
*/

#include "HX711.h" //Original Repository Created by Bodge https://github.com/bogde/HX711
#include "openscale.h" //Contains EPPROM locations for settings
#include <Wire.h> //Needed to talk to on board TMP102 temp sensor
#include <EEPROM.h> //Needed to record user settings
#include <OneWire.h> //Needed to read DS18B20 temp sensors

#include <avr/sleep.h> //Needed for sleep_mode
#include <avr/power.h> //Needed for powering down perihperals such as the ADC/TWI and Timers

#define FIRMWARE_VERSION "1.2"

//Global variables
//-=-=-=-=-=-=-=-=-=-=-=-=-=-=-=-=-=-=-=-=-=-=-=-=-=-=-=-=-=-=-=-=-=-=-
long setting_uart_speed; //This is the baud rate that the system runs at, default is 9600. Can be 1,200 to 1,000,000
byte setting_units; //Lbs or kg?
unsigned int setting_report_rate;
long setting_calibration_factor; //Value used to convert the load cell reading to lbs or kg
long setting_tare_point; //Zero value that is found when scale is tared
boolean setting_timestamp_enable; //Prints the number of miliseconds since boot next to weight reading
byte setting_decimal_places; //How many decimals to display
byte setting_average_amount; //How many readings to take before reporting reading
byte setting_local_temp_enable; //Prints the local temperature in C
byte setting_remote_temp_enable; //Prints the remote temperature in C
byte setting_status_enable; //Turns on/off the blinking status LED
byte setting_serial_trigger_enable; //Takes reading when serial character is received
byte setting_raw_reading_enable; //Prints the raw, 24bit, long from the HX711, ex: 8355808
byte setting_trigger_character; //The character that will cause OpenScale to report a reading
boolean setupMode = false; //This is set to true if user presses x

const byte escape_character = 'x'; //This is the ASCII character we look for to break reporting
const int minimum_powercycle_time = 500; //Anything less than 500 can cause reading problems
//-=-=-=-=-=-=-=-=-=-=-=-=-=-=-=-=-=-=-=-=-=-=-=-=-=-=-=-=-=-=-=-=-=-=-

const byte statusLED = 13;  //Flashes with each reading

HX711 scale; //Setup interface to scale

OneWire remoteSensor(4);  //Setup reading one wire temp sensor on pin 4 (a 4.7K resistor is necessary)
byte remoteSensorAddress[8];
boolean remoteSensorAttached = false;

void setup()
{
  pinMode(statusLED, OUTPUT);

  scale.begin(DAT, CLK);

  //Power down various bits of hardware to lower power usage
  set_sleep_mode(SLEEP_MODE_IDLE);
  sleep_enable();

  //Shut off Timer2, Timer1, ADC
  ADCSRA &= ~(1 << ADEN); //Disable ADC
  ACSR = (1 << ACD); //Disable the analog comparator
  DIDR0 = 0x3F; //Disable digital input buffers on all ADC0-ADC5 pins
  DIDR1 = (1 << AIN1D) | (1 << AIN0D); //Disable digital input buffer on AIN1/0

  power_timer1_disable();
  power_timer2_disable();
  power_adc_disable();
  power_spi_disable();

  //During testing reset everything
  //for(int x = 0 ; x < 30 ; x++)
  //  EEPROM.write(x, 0xFF);

  Wire.begin();

  readSystemSettings(); //Load all system settings from EEPROM

  //Setup UART
  Serial.begin(setting_uart_speed);
  displaySystemHeader(); //Product title and firmware version

  checkEmergencyReset(); //Look to see if the RX pin is being pulled low

  scale.set_scale(setting_calibration_factor);
  scale.set_offset(setting_tare_point);

  //Calculate the minimum time between reports
  int minTime = calcMinimumReadTime();
  Serial.print(F("Minimum time between reports: "));
  Serial.println(minTime);

  //Look for a special case where the report rate time is less than the allowed minimum
  if (setting_report_rate < minTime) setting_report_rate = minTime;

  Serial.print(F("Press "));
  Serial.print((char)escape_character);
  Serial.println(F(" to bring up settings"));

  Serial.println(F("Readings:"));

  powerUpScale(); //Be sure the scale is powered up
}
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

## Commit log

2024-06-17 RFID works with this scale doesn't
    [read_5.py]
2024-06-19 2. I changed the code so that it listens to the RFID-Reader all the time and not just after the start button is pushed.
    1. Bugs seem to be fixed now
    Eventually we need to add a function that deletes all .txt files to troubleshoot an issue that sometimes occurs when the code wasn't completely executed before. (.txt files are not empty then)
2024-07-10 Autopilot added
    [1234.xlsx, General.xlsx]
2024-07-10 Autopilot update
    [1234.xlsx, General.xlsx]
2024-07-10 UDP on pc side - communicating with rfid and weighing systems via MATLAB - some change in GUI
    [1234.xlsx, General.xlsx]
2024-07-16 Update AutoPilot.mlapp
    Start Button gets disabled now, if information are missing
2024-07-16 Update AutoPilot.mlapp
    Design was changed.
    Weigh again Button not necessary anymore.
    RFID is listening continuously now.
    Start Button is only enabled when all Text Areas have Text in them (that doesn't work properly at the moment)
    Communication with Excel files to load the right Subject ID(not RFID), Protocol and Settings is still missing (via UDP from the "Project Manager" PC/Server)
    This has to be done with Fatemeh.
2024-07-18 Update AutoPilot.mlapp
    start button only available with valid input now
2024-07-24 Update AutoPilot.mlapp
    Load Data Button only available if RFID and Weight Text areas have values that make sense
2024-07-29 few changes in GUI
    calibration does not work yet
    Button to enable ID field has to be implemented (for animals without RFID)
2024-08-02 Tare Button
    Taring works now but weighing after doesn't
    Serial connection isn't closed anymore
    COMPARE WITH OLDER VERSION!!!
2024-08-05 update Autopilot
    Everything should work now
    Still some errors after closing but they don't seem to make any issues
    Command window doesn't react while GUI is running (not sure if fixable)
    Automatic USB Detection, Folder Detection and Calibration Button are coming soon
2024-08-06 calibration button in work
2024-08-08 Update AutoPilot.mlapp
    closes now, if manual button or start button are pushed
2024-08-09 update
    Start of function to send performance BpodObject to Server
    Calibration changes commas in user input to dots to avoid errors
2024-08-09 Update AutoPilot.mlapp
    only valid input accepted during calibration
2024-08-09 Update AutoPilot.mlapp
    fixed calibration error for false input
2024-08-12 Update AutoPilot.mlapp
    Calibration and Taring is faster now
2024-08-29 added a button to open the screen keyboard
2024-08-30 Addded Arduino codes to detect devices
    [SparkFun_OpenScale_Panel_v10.brd, SparkFun_openScale.brd, SparkFun_openScale.sch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]
2024-09-17 changing stage possibility added
2024-09-17 change stage
2024-10-17 Touchshaker PCB design
2024-10-17 Create musallGroup PuffyPenguin main pcb-Breakout.zip
2024-10-17 PCB Boxes added
    [01 - Ethernet Side.dxf, 02 - Input Module Side.dxf, 03 - Panel Top.dxf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]
2024-11-08 Create Assembled Touch shaker box v32.stl
2024-11-24 added Breakout PCB files
2024-11-25 new Touchshaker PCB Design added
2024-12-02 PD holders added
    [PD Holder Thin.stl, PD Holder.stl]
2024-12-03 dlc model added
    [CollectedData_Elisa.csv, learning_stats.csv]
2024-12-13 UDP Server part updated
    [1234.xlsx, General.xlsx, IDConvertor.xlsx]
2024-12-13 clean up
    [01 - Ethernet Side.dxf, 02 - Input Module Side.dxf, 03 - Panel Top.dxf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]
2025-11-07 Updated PCB Files and Box.stls
    [01 - Ethernet Side.dxf, 02 - Input Module Side.dxf, 03 - Panel Top.dxf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]
2025-11-11 Box Parts added
    [Bottom v1.stl, Breakout_Bottom v1.stl, Breakout_Lid v1.stl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]
2026-03-06 Updated PCB data
    [BOM.ods, Bpod Controller v3 BOM.csv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]
2026-03-09 Added KiCAD files
    [Breakout_v4.PrjPcb, Breakout_v4.SchDoc, Breakout_v4.step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]
2026-07-27 Restructure repo into docs/software/firmware/hardware/third_party layout
    Reorganizes the flat, inconsistently-named tree into a conventional
    top-level split, and adds baseline repo hygiene:
    - docs/, software/{autopilot,udp,bpod_local}, firmware/{touchshaker,
    rfid_scale,openscale}, hardware/{breakout,touchshaker,platform},
    third_party/bpod_gen2
    - Drop superseded "*_old" PCB folders (recoverable from git history),
    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
    [1234.xlsx, Arrange.stl, BOM.ods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]
2026-07-27 Improve manual and README text, descriptions, and structure
    docs/MANUAL.md:
    - Add a "how this manual is organized" note up top
    - Drop leftover paper-style phrasing ("proposed setup") for plain
    build-instruction voice
    - Re-embed the breakout PCB image at the resistor-soldering step
    instead of pointing back up the page
    - Add short lead-in descriptions to sections that jumped straight
    into a parts list (Platform, Rotary encoder and wheel, Motors and
    Spouts, Tactile stimuli system, Water providing system)
    - Fix inconsistent "List of components" styling under Visual/Auditory
    (was bold text, now a proper heading matching Breakout Box, and
    added to the TOC)
    - Add a new "Running a sessio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
2026-07-27 Add safety notes, folder READMEs, citation, and TODO(you) content gaps
    - Add safety callouts for the hot-air-gun IR filter removal step and
    the compressed-air tactile system
    - Add a Requirements section and TODO(you) markers at every spot that
    needs content only the maintainer can supply: MATLAB/toolchain
    prerequisites, an assembled-setup overview photo, the thinner
    Touchshaker Box tools/steps, and the missing Labcams installer
    files / visual-stimuli Python code (upgraded from informational
    notes to the same actionable TODO(you) tag for consistency)
    README.md:
    - Add a Getting started section (clone, submodule init, manual link)
    - Add a Citation section with the p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

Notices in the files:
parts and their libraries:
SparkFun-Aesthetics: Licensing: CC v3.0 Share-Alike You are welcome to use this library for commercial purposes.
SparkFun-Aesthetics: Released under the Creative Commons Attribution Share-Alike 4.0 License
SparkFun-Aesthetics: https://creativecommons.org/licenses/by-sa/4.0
